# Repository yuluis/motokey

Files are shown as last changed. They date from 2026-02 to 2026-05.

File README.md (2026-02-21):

# MotoKey — Aftermarket E-Moto Security System

Encrypted keycard lock for electric motorcycles. Cut the power, pocket the key.

**Live site:** https://kindro.store
**Hardware design:** https://kindro.store/hardware-design.html

---

## What Is This

MotoKey is an aftermarket security system for electric mopeds/motorcycles/scooters. It's a small weatherproof box that wires inline with the battery and cuts power unless an encrypted key fob is nearby. No key = no power = bike doesn't move.

Every kit ships with:
- 1 lock box (mounts on bike, inline with battery)
- 2 encrypted key fobs (pocket/keychain sized)
- Mounting kit (bracket, zip ties, adhesive, wire terminals, heat shrink)
- Instruction card with QR link to install video

Two products:
| Product | Price | Key Difference |
|---|---|---|
| **MotoKey Basic** | $89 | AES-128, single relay, CR2032 fob, 30ft range |
| **MotoKey Enhanced** | $149 | AES-256, dual relay + tamper alert, USB-C fob, 50ft range, 3 fobs |

---

## Origin

This project started as a learning exercise between Luis and Julio on 2026-02-21. The goal: use AI (Claude) to go from idea to live website to hardware design in a single session.

**The conversation:**
- Julio builds aftermarket e-motos and wanted a keycard security system to sell
- Start with two versions: a basic remote and an enhanced remote
- Key fobs should be small (keychain/pocket dongle)
- The lock box connects to the battery with a simple power-cut circuit
- Must be weatherproof (outdoor bike use)
- Programming between keycard and hardware must be secured to prevent hacking
- Comes with 2 keys and a mounting kit

**What got built in this session:**
1. Product storefront website (static HTML/CSS/JS)
2. Full hardware architecture with real component selection
3. Security protocol design (AES-128 rolling codes, challenge-response)
4. Bill of materials with per-unit costs
5. Margin analysis proving profitability at $89/$149
6. Pushed to GitHub, deployed to production at kindro.store

---

## How It Works

### The Lock Box

Wires inline with the bike's main battery positive cable. Contains:
- **ATmega328P** microcontroller (same chip as Arduino)
- **SYN480R** 433MHz RF receiver
- **JQX-62F** 80A automotive relay (normally OPEN = locked)
- **LM2596** buck converter (48-72V battery → 5V logic)
- **AT24C256** EEPROM (stores up to 8 paired key records)
- Status LED + recessed pair button

The relay defaults to **open** (no power). When a valid key fob signal is received, the relay closes and power flows. When the key fob is out of range for 30 seconds, the relay opens and the bike is locked.

Cutting the wires doesn't help — the relay is normally open, so cutting anything just keeps the bike dead.

### The Key Fob

Small enough for a keychain. Contains:
- **ATtiny85** microcontroller (1.8μA sleep current)
- **SYN115** 433MHz RF transmitter
- **CR2032** coin cell battery (~18 month life)
- Single button

Press the button → MCU wakes from sleep → encrypts (counter + device ID) with the shared AES key → transmits 16-byte packet → goes back to sleep. Total active time: ~50ms.

### Security Protocol

**Pairing (one-time):**
1. Press PAIR button on lock box (LED blinks fast)
2. Press button on key fob
3. Lock box generates random 128-bit key
4. Key transfers to fob via physical contact (NFC/wired — can't intercept from distance)
5. Both devices store shared secret + set counter to 0

**Unlock (every use):**
1. Fob increments counter, encrypts (counter + fob ID) with shared key
2. Transmits encrypted packet over 433MHz
3. Lock box decrypts, verifies fob ID, checks counter > last seen
4. If valid: close relay (power on), start 30-sec timeout

**Why it's secure:**
- **Replay attack** → Fails. Counter already advanced. Old codes rejected.
- **Brute force** → AES-128 = 3.4×10³⁸ possible keys. Would take 10²² years at 1 billion attempts/sec.
- **Signal capture** → Every packet looks like random noise. No patterns.
- **Physical tamper** → Electronics potted in epoxy. Cracking the box destroys the circuits.
- **Wire bypass** → Relay is normally open. Cutting wires = bike stays dead.

---

## Economics

### Bill of Materials (at 100 units)

**Lock Box:** $10.80
| Component | Part | Cost |
|---|---|---|
| MCU | ATmega328P-AU | $1.40 |
| RF Receiver | SYN480R 433MHz | $0.50 |
| Relay | JQX-62F 80A | $2.80 |
| Relay Driver | 2N2222A + 1N4007 | $0.10 |
| Voltage Reg | LM2596 buck module | $0.80 |
| EEPROM | AT24C256 | $0.25 |
| Crystal | 16MHz + caps | $0.15 |
| LED + Button | Bicolor + tactile | $0.18 |
| Screw Terminals | 5mm pitch x2 | $0.30 |
| Wire Leads | 10AWG silicone x2 | $0.60 |
| Antenna | 17cm wire | $0.02 |
| PCB | 2-layer 50x40mm (JLCPCB) | $0.80 |
| Enclosure | ABS IP65 80x60x30mm | $1.80 |
| Cable Glands | PG7 nylon x2 | $0.20 |
| Potting | Urethane 2-part ~30ml | $0.50 |
| Misc | Caps, resistors, header | $0.40 |

**Key Fob (x1):** $2.37
| Component | Part | Cost |
|---|---|---|
| MCU | ATtiny85-20SU | $0.65 |
| RF Transmitter | SYN115 433MHz | $0.35 |
| Battery Holder | CR2032 SMD | $0.12 |
| Battery | CR2032 | $0.20 |
| Button | Tactile SMD 4x4mm | $0.05 |
| PCB | 2-layer 35x20mm | $0.40 |
| Enclosure | ABS fob case + keyring | $0.45 |
| Misc | Caps, resistors | $0.15 |

**Mounting Kit:** $1.60 | **Packaging:** $1.20

### Margin Analysis

| | Basic ($89) | Enhanced ($149) |
|---|---|---|
| BOM + materials | $18.34 | $31.10 |
| Assembly + QC | $5.00 | $8.25 |
| **Total COGS** | **$23.34** | **$39.35** |
| **Gross margin** | **$65.66 (73.8%)** | **$109.65 (73.6%)** |

At even 10 hand-built units ($30 COGS), the Basic still clears $59/unit.

---

## Next Steps for Julio

### Phase 1: Prototype (Weekends 1-2) — ~$35

Buy from Amazon/AliExpress:
- Arduino Nano (ATmega328P dev board) — $5
- 433MHz TX/RX module pair — $3
- 80A automotive relay module — $6
- ATtiny85 dev board (Digispark) — $4
- LM2596 buck converter module — $2
- Breadboard + jumper wires — $5
- CR2032 battery + holder — $2
- Push buttons + LEDs + resistors — $3
- ABS project box — $3
- Key fob cases (2-pack) — $2

Also need (one-time): USB-ASP programmer (~$8), soldering iron if you don't have one.

**Weekend 1: Proof of concept**
- Wire Arduino Nano + relay on breadboard
- Wire ATtiny85 + 433MHz TX on second breadboard
- Write basic TX/RX code (no encryption yet)
- Goal: press fob button → relay clicks → LED lights up

**Weekend 2: Add security**
- Add AES-128 library to both MCUs (use `tiny-AES-c` library)
- Hardcode a shared test key
- Implement rolling counter
- Verify that replaying a captured signal is rejected

### Phase 2: Complete Product (Weekends 3-4)

**Weekend 3: Pairing + polish**
- Add pair button logic on lock box
- Implement key exchange (wired connection for prototype)
- Add LED status states (green=unlocked, red=locked, blink=pairing)
- Add 30-second auto-lock timeout
- Add EEPROM storage for paired keys (support up to 8)

**Weekend 4: Enclosure + real test**
- Solder onto perfboard (replace breadboard)
- Mount in ABS project box with cable glands
- Fit fob circuit into key fob case
- Test with actual e-moto (or 48V bench supply)
- Range test through walls (target: 20-30m)
- Seal with potting compound

### Phase 3: First Production Run (Week 5-6)

- Order custom PCBs from JLCPCB (5-day turnaround, ~$0.80/board at 100 qty)
- Order components from LCSC (ships with PCBs)
- Assemble 10 units
- Create install video (phone camera is fine, post to YouTube)
- Print instruction cards with QR code to video

### Phase 4: Website + Sales

- Update kindro.store with real product photos
- Add Stripe payment integration (or start with PayPal/Venmo for simplicity)
- Post on e-moto forums, Facebook groups, Reddit r/ebikes r/emotorcycles
- List on eBay/Amazon if volume justifies it

---

## Plan to Sell the First 10 Units

### Target Customer
Owners of Chinese-brand electric mopeds/scooters (Onyx, Monday Motorbikes, Super73-adjacent, Sur-Ron, Talaria, generic 48V-72V e-motos) who currently have zero theft protection.

### Pricing Strategy
- **Launch price: $79 Basic / $129 Enhanced** (introductory discount)
- After first 10 units and reviews: raise to $89 / $149
- Bundle deal: Basic + Extra Fob 2-pack for $99

### Sales Channels (ranked by effort vs return)

**1. E-moto Facebook groups (free, highest conversion)**
- Join: "Sur-Ron Owners Group", "Onyx Motorbikes Owners", "Electric Motorcycle Riders", "E-bike Security"
- Post a demo video: "I made an aftermarket kill switch for my [bike]. Press fob = power. Walk away = dead. $79."
- Engage with theft complaint posts (there are many)
- Offer first 5 buyers a discount for honest reviews

**2. Reddit (free, wide reach)**
- r/ebikes (750K+ members), r/surron, r/emotorcycles, r/ElectricScooters
- Post as "I built this" with demo video/gif
- Link to site in comments (not title — Reddit hates direct sales posts)

**3. Local e-moto shops / repair shops**
- Leave 2 demo units at local shops on consignment
- They sell for $89, keep $15 commission
- Julio's existing network of people who build aftermarket e-motos

**4. eBay listing**
- Low effort to set up
- "Electric Motorcycle Security Kill Switch - Encrypted Key Fob - Aftermarket Anti-Theft"
- eBay takes ~13% but handles payments and provides buyer trust

**5. YouTube install video**
- Film installing MotoKey on an actual e-moto (3-5 min)
- Title: "DIY Anti-Theft for Electric Motorcycles - $79 Kill Switch Install"
- Description links to kindro.store
- This becomes the long-tail discovery channel

### First 10 Units — Concrete Plan

| Unit | Channel | Price | Notes |
|---|---|---|---|
| 1 | Personal use / demo | $0 | Install on Julio's bike for demo videos |
| 2 | Consignment at local shop | $89 | Leave with a shop Julio trusts |
| 3-5 | Facebook groups | $79 | Launch price, ask for reviews |
| 6-7 | Reddit posts | $79 | Link to kindro.store |
| 8 | eBay | $89 | Test marketplace demand |
| 9-10 | Word of mouth / referral | $79 | Offer $10 referral to early buyers |

### Revenue from first 10

| | Units | Revenue |
|---|---|---|
| Demo unit | 1 | $0 |
| At $79 | 7 | $553 |
| At $89 | 2 | $178 |
| **Total** | **10** | **$731** |
| COGS (10 units @ ~$30 hand-built) | | -$300 |
| **Net profit** | | **$431** |

That $431 funds the next batch of 25-50 units at proper PCB pricing, which drops COGS to ~$23/unit and margin jumps to 74%.

### Marketing Assets Needed
1. **Demo video** (30 sec): Press fob → bike powers on. Walk away → bike dies. Film on actual e-moto.
2. **Install video** (3-5 min): Full install process. Phone camera is fine.
3. **Product photos**: Lock box, fobs, complete kit in packaging. Natural light, clean background.
4. **One-liner**: "Encrypted kill switch for your e-moto. $79. Two keys included."

---

## Tech Stack (Website)

- Static HTML + CSS + JavaScript (no framework, no build step)
- Hosted on DigitalOcean VPS behind nginx
- Domain: kindro.store (SSL via Let's Encrypt)

---

## Repository Structure

```
motokey/
├── index.html              # Product storefront
├── style.css               # Storefront styles
├── app.js                  # Cart + FAQ interactivity
├── hardware-design.html    # Full hardware architecture document
├── .gitignore
└── README.md               # This file
```

---

## Built With

This entire project — website, hardware architecture, security protocol, BOM, margin analysis, and go-to-market plan — was designed in a single AI-assisted session using [Claude Code](https://claude.com/claude-code).

The goal was to demonstrate how to go from conversation to live product in one sitting:
1. Discussed the idea → 2. Built the website → 3. Pushed to GitHub → 4. Deployed to production → 5. Designed the hardware → 6. Wrote the business plan

Total time: one session. Total code written by hand: zero.

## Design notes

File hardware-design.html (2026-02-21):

← Back to storefront

# MotoKey Hardware Architecture

MVP design with real components. Goal: build cheap, sell profitably at $89 / $149.

## 1 System Overview

The whole system is three things: a lock box on the bike, a key fob in your pocket, and a security protocol binding them together. That's it.

Key Design Decision:

One-way RF (fob transmits, box receives). This is half the cost of two-way communication and the fob battery lasts 3x longer. The tradeoff: no confirmation beep from the bike. The LED on the lock box blinks instead. For $89, this is the right call.

## 2 Lock Box Architecture

## 3 Key Fob Architecture

## 4 Security Protocol

This is what prevents someone from cloning the fob or replaying a captured signal.

### Pairing (one-time setup)

  FOB                                    LOCK BOX
   │                                        │
   │  1. User presses PAIR button on box    │
   │         LED blinks fast (green)        │
   │                                        │
   │  2. User presses FOB button            │
   │  ──── plaintext: "PAIR_REQUEST" ─────► │
   │                                        │
   │  3. Box generates random 128-bit key   │
   │     Box stores: KEY + FOB_ID           │
   │     Box shows LED pattern:             │
   │     (4 blinks = key byte checksum)     │
   │                                        │
   │  4. Box transmits key via IR/NFC       │
   │  ◄──── one-time key transfer ────────  │  ← requires physical contact
   │                                        │
   │  5. Fob stores KEY in EEPROM           │
   │     Both set counter = 0               │
   │                                        │
   │  DONE. Shared secret established.      │
   └────────────────────────────────────────┘

   NOTE: Key transfer via NFC/physical contact means an attacker
   cannot intercept the pairing from a distance. You must be
   holding the fob against the box.

### Unlock (every use)

  FOB                                    LOCK BOX
   │                                        │
   │  1. User presses button                │
   │     Fob increments counter             │
   │     Fob computes:                      │
   │       payload = counter | FOB_ID       │
   │       encrypted = AES-128(KEY, payload)│
   │                                        │
   │  ──── 433MHz: encrypted packet ──────► │
   │       (16 bytes, ~3ms air time)        │
   │                                        │
   │  2. Box decrypts with stored KEY       │
   │     Checks FOB_ID matches              │
   │     Checks counter > last_counter      │
   │     If valid:                          │
   │       - Update last_counter            │
   │       - Close relay (power ON)         │
   │       - Start 30-second timeout        │
   │       - LED solid green                │
   │                                        │
   │  3. After 30 sec with no new signal:   │
   │     - Open relay (power OFF)           │
   │     - LED blink red                    │
   │                                        │
   └────────────────────────────────────────┘

### Why this is hard to hack

#### Replay Attack

Attacker records a valid transmission and replays it. Fails because the counter has already advanced. The lock box rejects any counter ≤ last seen.

#### Brute Force

AES-128 has 2¹²⁸ possible keys = 3.4 × 10³⁸. At 1 billion attempts/second, it would take 10²² years. The universe is 1.4 × 10¹⁰ years old.

#### Signal Analysis

Every transmission looks like random noise. No pattern emerges even with millions of captured packets. AES is the same encryption used by the US government for classified data.

#### Physical Bypass

Relay is normally-open. Cutting wires = no power. Cracking the potted enclosure destroys the PCB. The only bypass is splicing around the entire box, which requires stripping the bike apart.

## 5 Bill of Materials & Cost

### Lock Box BOM

Component | Part | Qty | Unit Cost | Notes
MCU | ATmega328P-AU (TQFP) | 1 | $1.40 | Same chip as Arduino. Massive ecosystem, easy to program.
RF Receiver | SYN480R 433MHz | 1 | $0.50 | Superheterodyne ASK receiver. Better range than SRX882.
Relay | JQX-62F 80A SPST-NO | 1 | $2.80 | Automotive-grade. 12V coil. Handles 48-72V DC switching.
Relay Driver | 2N2222A + 1N4007 flyback | 1 | $0.10 | NPN transistor drives relay coil from MCU GPIO.
Voltage Regulator | LM2596 buck module | 1 | $0.80 | 48-72V input → 5V output. Pre-built module.
EEPROM | AT24C256 (I2C) | 1 | $0.25 | Stores up to 8 paired key records. Non-volatile.
Crystal | 16MHz + 22pF caps | 1 | $0.15 | MCU clock source.
LED | Bicolor red/green 3mm | 1 | $0.08 | Status indicator. Two resistors.
Button | Tactile switch (recessed) | 1 | $0.10 | Pairing button. Recessed to prevent accidental press.
Screw Terminals | 5mm pitch, 2-pos | 2 | $0.30 | Battery in + controller out. Accepts 10AWG.
Wire Leads | 10AWG silicone, 15cm ea | 2 | $0.60 | Pre-tinned, red + green.
Antenna | 17cm wire (1/4 wave) | 1 | $0.02 | Just a piece of wire. Cut to 17.3cm for 433MHz.
PCB | Custom 2-layer, 50x40mm | 1 | $0.80 | JLCPCB @ 100 qty. FR4, 1.6mm, HASL.
Enclosure | ABS IP65 box, 80x60x30mm | 1 | $1.80 | Off-shelf waterproof junction box. Black.
Cable Glands | PG7 nylon | 2 | $0.20 | Waterproof wire pass-through.
Potting Compound | Urethane 2-part | ~30ml | $0.50 | Fills enclosure. Tamper-proof + weather seal.
Misc | Caps, resistors, header, solder | - | $0.40 | Decoupling caps, pull-ups, ISP header.
Lock Box Subtotal | | | $10.80

### Key Fob BOM (x1)

Component | Part | Qty | Unit Cost | Notes
MCU | ATtiny85-20SU (SOIC) | 1 | $0.65 | 8-pin, 8KB flash. Runs AES in software. 1.8μA sleep.
RF Transmitter | SYN115 433MHz | 1 | $0.35 | ASK transmitter. 10mW. Tiny SOT-23 package.
Battery Holder | CR2032 SMD holder | 1 | $0.12 | Bottom-mount for thin profile.
Battery | CR2032 lithium | 1 | $0.20 | Included. 225mAh, ~18 month life.
Button | Tactile SMD 4x4mm | 1 | $0.05 | Main unlock button. Wake from sleep.
Antenna | PCB trace | 1 | $0.00 | Etched into PCB. No extra cost.
PCB | Custom 2-layer, 35x20mm | 1 | $0.40 | JLCPCB @ 100 qty. Small board.
Enclosure | ABS key fob case + keyring | 1 | $0.45 | Off-shelf injection molded fob case. Black.
Misc | Caps, resistors | - | $0.15 | Decoupling, pull-up.
Key Fob Subtotal (x1) | | | $2.37

### Mounting Kit BOM

Component | Part | Qty | Unit Cost | Notes
Mounting Bracket | Stainless L-bracket | 1 | $0.40 | Screw-mount to frame.
Zip Ties | UV-resistant nylon, 200mm | 6 | $0.15 | Backup / alternative mounting.
Adhesive Pad | 3M VHB double-sided | 1 | $0.30 | For flat-surface mounting.
Heat Shrink | Assorted, adhesive-lined | 4pc | $0.20 | Weatherproof wire splices.
Ring Terminals | 10AWG, M6 | 4 | $0.40 | Optional: bolt directly to battery terminals.
Instruction Card | Printed card, double-sided | 1 | $0.15 | Install guide + QR to video.
Mounting Kit Subtotal | | | $1.60

### Packaging

Component | Part | Qty | Unit Cost | Notes
Box | Custom printed corrugated | 1 | $0.80 | Branded box, 150x120x60mm
Insert | Die-cut foam insert | 1 | $0.40 | Holds lock box + 2 fobs + kit
Packaging Subtotal | | | $1.20

## 6 Cost Rollup & Margin Analysis

### MotoKey Basic — Retail $89

Line Item | Cost
Lock Box (assembled) | $10.80
Key Fob x 2 | $4.74
Mounting Kit | $1.60
Packaging | $1.20
Assembly labor (15 min @ $15/hr) | $3.75
Testing & QC (5 min) | $1.25
Total COGS | $23.34
Retail Price | $89.00
Gross Margin | $65.66 (73.8%)

### MotoKey Enhanced — Retail $149

Line Item | Cost
Lock Box (upgraded: dual relay, STM32L4, vibration sensor) | $16.50
Key Fob x 2 (USB-C rechargeable, LED) + 1 backup fob (basic) | $11.20
Mounting Kit | $1.60
Packaging (premium) | $1.80
Assembly labor (25 min @ $15/hr) | $6.25
Testing & QC (8 min) | $2.00
Total COGS | $39.35
Retail Price | $149.00
Gross Margin | $109.65 (73.6%)

Prototype pricing note:

BOM costs above assume ordering 100 units from LCSC/JLCPCB. For a single prototype, expect 2-3x these prices (~$50-60 for one complete Basic kit from Mouser/DigiKey). But the per-unit math works beautifully at even small scale. At 100 units you're already at 73% margin.

## 7 First Prototype — What to Buy

To build one working prototype on your desk for under $40:

### Shopping List (DigiKey/Amazon/AliExpress)

Item | Source | ~Price
Arduino Nano (ATmega328P dev board) | Amazon | $5
433MHz TX/RX module pair (SYN115 + SYN480R) | Amazon/AliExpress | $3
5V 80A relay module (automotive) | Amazon | $6
ATtiny85 dev board (Digispark) | Amazon | $4
LM2596 buck converter module | Amazon | $2
Breadboard + jumper wires | Amazon | $5
CR2032 battery + holder | Amazon | $2
Push buttons (assorted) | Amazon | $2
LED + resistors | Amazon | $1
ABS project box | Amazon | $3
Key fob cases (2-pack) | AliExpress | $2
Prototype Total | | ~$35

Dev tools you'll also need (one-time):

USB-ASP programmer for the ATtiny85 (~$8). The Arduino Nano programs via USB directly. Soldering iron if you don't have one. Total one-time tool cost: ~$20-30.

### Prototype Build Order

  PHASE 1: Proof of Concept (Weekend 1)
  ──────────────────────────────────────
  ✦ Wire Arduino Nano + relay on breadboard
  ✦ Wire ATtiny85 + 433MHz TX on breadboard
  ✦ Write simple TX/RX code (no encryption yet)
  ✦ Press button on fob → relay clicks → LED turns on
  ✦ SUCCESS = "it works" demo

  PHASE 2: Security Layer (Weekend 2)
  ──────────────────────────────────────
  ✦ Add AES-128 library to both MCUs
  ✦ Hardcode a shared key for testing
  ✦ Implement rolling counter
  ✦ Verify: replaying a captured signal fails
  ✦ SUCCESS = "it's secure" demo

  PHASE 3: Pairing + Polish (Weekend 3)
  ──────────────────────────────────────
  ✦ Add pair button logic
  ✦ Implement key exchange (wired for prototype, NFC for production)
  ✦ Add LED status states
  ✦ Add 30-second auto-lock timeout
  ✦ Add EEPROM storage for paired keys
  ✦ SUCCESS = complete working unit

  PHASE 4: Enclosure + Test (Weekend 4)
  ──────────────────────────────────────
  ✦ Solder onto perfboard (ditch breadboard)
  ✦ Mount in ABS enclosure
  ✦ Fit fob PCB in key fob case
  ✦ Test with actual e-moto battery (48V bench supply or real bike)
  ✦ Range test (should get 20-30m through walls)
  ✦ SUCCESS = "ship it" prototype

## 8 Physical Layout

### Lock Box (top view, lid off)

┌──────────────────────────────────────────┐
│  ○ PAIR            ○ LED                 │  ← lid (buttons/LED)
│  btn               R/G                   │
├──────────────────────────────────────────┤
│                                          │
│  ┌─────────────┐  ┌───────────────────┐  │
│  │  LM2596     │  │   ATmega328P      │  │
│  │  buck       │  │   + crystal       │  │
│  │  48V→5V     │  │   + EEPROM        │  │
│  └─────────────┘  │   + SYN480R RX    │  │
│                    │                   │  │
│                    │         ┌antenna  │  │
│                    └────────┘         ─┤  │
│                                          │
│  ┌──────────────────────────────────┐    │
│  │                                  │    │
│  │      JQX-62F  80A  RELAY        │    │
│  │                                  │    │
│  └──────────────────────────────────┘    │
│                                          │
│  [RED IN]                    [GREEN OUT]  │  ← screw terminals
│    ║                              ║      │    through cable glands
└════╩══════════════════════════════╩══════┘
     ↑                              ↑
   BAT+                          CTRL+
   10AWG                         10AWG

### Key Fob (internal view)

    ○ ← keyring hole
┌──────────────────────┐
│                      │
│  ┌────────────────┐  │
│  │    ATtiny85    │  │
│  │                │  │
│  │  ┌──────────┐  │  │
│  │  │ SYN115   │  │  │
│  │  │ TX       │  │  │
│  │  └──────────┘  │  │
│  │                │  │
│  │  ~~~antenna~~  │  │  ← PCB trace
│  └────────────────┘  │
│                      │
│  ┌────────────────┐  │
│  │   CR2032       │  │  ← coin cell
│  │   battery      │  │    (bottom mount)
│  └────────────────┘  │
│                      │
│       [ BTN ]        │  ← main button
│                      │
└──────────────────────┘
   48mm x 30mm x 10mm

## 9 Scaling Considerations

#### 10 units (garage batch)

Hand-solder perfboard. Buy parts from Amazon. COGS ~$30/unit. Margin ~66% at $89.

#### 100 units (first real run)

Custom PCB from JLCPCB ($0.80/ea). Parts from LCSC. COGS ~$23/unit. Margin ~74% at $89.

#### 1000+ units

PCBA assembly (JLCPCB SMT). Custom injection mold enclosure. COGS drops to ~$15/unit. Margin ~83%.

Bottom line:

The Basic kit costs $23 to build at 100 qty and sells for $89. That's a 73% gross margin. Even selling 10 hand-built units at $30 COGS, you clear $59 per unit. The math works at every scale.

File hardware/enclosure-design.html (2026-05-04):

# MotoKey Lock Box — Enclosure Design v3

3D-printed castellated finger joint enclosure | 140x75x38mm | No drilling, no supports | 2026-03-11

## 1. Enclosure Overview

### External Dimensions

Length | 140 mm
Width | 75 mm
Height | 38 mm
Wall thickness | 2.5 mm
Corner radius | 3 mm
Split height | 19 mm

### Finger Joint

Finger width | 8 mm
Finger depth | 8 mm
Tolerance | 0.2 mm/side
Corners | Front/back own corners
Openings | 7 (auto at connectors)
Alignment | 2x 3mm pins

### Printing

Material | PETG or ABS
Layers | 0.2 mm
Walls | 3 perimeters
Infill | 20%
Supports | None needed
Orientation | Both open-side-up

## 2. Top View — Internal Layout with Modules

Top view with lid removed. GPS shown dashed because it mounts on the lid interior (faces sky). LoRa plugs into J4 header on PCB. Battery in printed cradle held by zip ties.

## 3. Side Cross-Section — Module Heights

Cross-section along long axis. Relay is tallest at 16mm. LoRa module sits on 8mm header pins. GPS mounts flat on lid interior with ceramic patch facing up (through plastic). Battery sits in printed cradle beside PCB.

## 4. Module Details

### LoRa — RFM95W

Module | RFM95W / Ra-01
Size | 16 x 16 x 3 mm
Interface | SPI (J4, 1x8 header)
Frequency | 915 MHz (US)
Antenna | Wire whip ~82mm
Position | Center-left of PCB
Height | ~11mm above PCB
Cost | ~$4

Plugs into J4 pin header. Keep away from relay (noise). Antenna runs along inside of enclosure wall. Optional: SMA bulkhead for external antenna.

### GPS — BN-220

Module | BN-220 / Quectel L80
Size | 22 x 20 x 6 mm
Interface | UART (J8, 1x4 header)
Antenna | Ceramic patch (integrated)
Position | Lid interior, front-left
Mount | Double-sided tape / shelf
Cable | ~60mm wire to J8
Cost | ~$5

Patch antenna MUST face sky. Plastic lid is RF-transparent. Mount flat against lid interior. Short cable to J8 on PCB.

### Battery — 18650

Cell | 18650 Li-ion
Size | 65 x 18 mm
Capacity | 2600 mAh typical
Charging | MCP73831 via USB
Position | Right side of enclosure
Mount | Printed cradle + 2x zip ties
Wires | 20AWG to BT1 pads
Runtime | ~50 hrs standby

Drops into semi-circular cradle. End walls prevent sliding. Two zip ties at 25% and 75% thread through floor channels and cinch over cell.

## 5. RF Placement Strategy

Key principle: GPS and LoRa in the quiet left zone, relay and buzzer in the noisy right zone, battery acts as a passive RF buffer between them. GND copper pour on both PCB layers provides shielding.

## 6. Wall Openings Map

### Front Wall (y = 0)

Opening | Position | Width | Purpose
Cable 1 | x = 49 | 10 mm | Sensor wires
Cable 2 | x = 84 | 10 mm | Zone wires

### Back Wall (y = 75)

Opening | Position | Width | Purpose
J1 | x = 20 | 12 mm | 12V power input
LEDs | x = 53 | 18 mm | LED1 + LED2 light pipes
J2 | x = 96 | 12 mm | Relay COM/NO/NC

### Left Wall (x = 0)

Opening | Position | Width | Purpose
J7 | y = 31 | 14 mm | USB Micro-B charging

### Right Wall (x = 140)

Opening | Position | Width | Purpose
Battery | y = 37.5 | 10 mm | Battery wire routing

## 7. Bill of Materials — Enclosure + Modules

Item | Qty | Spec | Est. Cost
3D printed base | 1 | 140x75x19mm, PETG/ABS | $3-5
3D printed lid | 1 | 140x75x19mm, PETG/ABS | $3-5
RFM95W LoRa module | 1 | SX1278, 915MHz, SPI | $4
BN-220 GPS module | 1 | Integrated patch antenna, UART | $5
18650 Li-ion cell | 1 | 2600mAh, unprotected | $3
Wire antenna | 1 | ~82mm for 915MHz quarter-wave | $0
Zip ties (small) | 2 | 100mm, for battery hold-down | $0.10
M3x8 self-tap screws | 4 | PCB standoff (optional, friction fit) | $0.20
Double-sided tape | 1 | 3M VHB, for GPS on lid | $0.10
20AWG wire | 100mm | Battery leads (red + black) | $0.05
Total enclosure + modules + battery | | | $18-22

## 8. Assembly Notes

- No drilling. All openings are formed by finger joint gaps — printed in place.
- No supports. Both pieces print open-side-up. All features are vertical extrusions.
- Mount PCB on 4x standoffs in base (press-fit or self-tap M3 screws)
- Plug LoRa module (RFM95W) into J4 header. Route antenna wire along left wall interior.
- Stick GPS module (BN-220) to lid interior with VHB tape, front-left corner. Cable to J8.
- Drop 18650 cell into cradle. Thread 2x zip ties through floor channels, cinch over cell.
- Solder battery wires (20AWG, 50mm) from cell to BT1 pads on PCB
- Route power wires (12V, relay) through back wall openings
- Press lid down — fingers interleave with base, alignment pins register position
- Optional: seal finger joint seams with silicone for weather resistance

For weather sealing: apply a thin bead of silicone to finger joint faces before closing. The tight finger mesh plus silicone provides good water resistance without gaskets.

MotoKey enclosure design v3 — 2026-03-11 | CAD: enclosure.scad (OpenSCAD)

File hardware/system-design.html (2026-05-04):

# MotoKey Controller — System Design

Generic encrypted rolling-code relay controller. Use cases: e-motorcycle kill switch, deadbolt lock, gate controller. Phase 1 (KeeLoq fob + buzzer) and Phase 2 (LoRa remote access).

## 1. The Problem

MotoKey is a generic encrypted rolling-code relay controller. The same PCB and firmware serves multiple use cases — the only difference is the enclosure and wiring harness.

E-Motorcycle Kill Switch

E-motos (Sur-Ron, Talaria, Zero, NIU) have no ignition key — they use a simple toggle switch or app. MotoKey intercepts the motor controller enable wire so the bike won't move without the owner's key fob.

Deadbolt / Gate Lock

Same controller drives an electric strike or motorized deadbolt. Relay output replaces the enable wire with the lock's power circuit. Walk-up fob unlock + optional LoRa remote access.

## 2. Where It Mounts

Installation Location

- Under the seat — every e-moto has space here, accessible for install, hidden from thieves
- Zip-tied or velcro-strapped to the frame — no drilling required
- Near the existing motor controller — short wire run to intercept the enable line
- Antenna wire routed up toward seat hinge for best RF reception

Critical Design Insight: Intercept the Enable Wire, NOT the Power Wire

E-motos run 48-72V at 40-100A to the motor. You do NOT want a relay switching that. Instead, every motor controller has a low-current enable/key wire (the existing ignition switch). MotoKey's relay (10A @ 5V) switches this enable wire. When the relay is open (armed), the motor controller stays off regardless of the main power switch.

## 3. Form Factor

Parameter | Spec
Enclosure size | 80 x 50 x 25 mm (fits in palm)
Material | ABS plastic, ultrasonic welded
Weight | ~65g including potting
Mounting | 4x M3 tabs + zip-tie slots (no drilling)
Sealing | Silicone gasket + potting compound
Cable entry | 2x PG7 cable glands with O-rings
LED | Visible through translucent window on top face
Learn button | Recessed pinhole (paperclip to press)

## 4. Main Interfaces

Interface | Connector | Purpose
J1 — Power | 2-pin screw terminal | 12V from e-moto accessory circuit
J2 — Relay Out | 3-pin screw terminal (COM/NO/NC) | Intercepts motor controller enable wire
J4 — Radio Module | 8-pin header | SX1278 LoRa/ASK module: VCC, GND, SPI bus (MOSI/MISO/SCK/NSS), RST, DIO0 (IRQ)
J3 — ICSP | 2x3 pin header | Factory firmware programming (internal)
SW1 — Learn | Pinhole tactile switch | Pair new key fobs
LED1/LED2 | Through translucent window | Red = armed, Green = unlocked
BZ1 — Buzzer | Passive piezo (on-board) | Audible beep (lock) / double-beep (unlock) confirmation
J5 — E-Paper (opt.) | 8-pin header | 1.54" e-ink display: VCC, GND, SPI (MOSI/SCK), CS, DC, RST, BUSY. Shows QR code for payments.
J6 — Zone Inputs | 7-pin header | 5 digital inputs (ZONE1-5) for NO/NC contact sensors (reed switches, door/window). +5V and GND for sensor power.
TH1 — Temp Sensor | On-board NTC | 10k NTC thermistor voltage divider on ADC6. Ambient temperature monitoring.
R8 — Light Sensor | On-board LDR | Photoresistor voltage divider on ADC7. Tamper detection (enclosure opened = light detected).
J8 — GPS (opt.) | 4-pin header | GPS receiver module: VCC, GND, TX→PD0(RXD), RX←PD1(TXD). Shares PD0/PD1 with ZONE3/ZONE4 — firmware selects mode.
J7 — USB Charge | USB Micro-B | LiPo battery charging input via MCP73831 (500mA). Charge only — no data lines.
BT1 — Battery | LiPo 3.7V cell | Optional backup battery. Powers system via Schottky diode-OR when 12V absent (~3.4V low-power mode).

## 5. How the User Uses It

## 6. Lock / Unlock State Machine

Fail-Secure Design

Power on → ARMED (relay open, motor disabled). This is the critical safety property. If power is lost, cut, or the controller fails, the relay opens and the bike can't move. A thief cannot bypass MotoKey by cutting its power wire — that just makes the bike more locked.

The ONLY way to enable the relay is: valid KeeLoq rolling code from a paired fob (or LoRaWAN command in Phase 2).

## 7. Diagnostics — LED + Buzzer

Two LEDs (red + green) visible through the enclosure window and a passive piezo buzzer (BZ1) communicate all states. The buzzer is driven by PWM on PD6 (OC0A) — different tone frequencies distinguish events.

LED Pattern | Buzzer | Meaning | User Action
RED solid | — | Armed (normal) | Press fob to unlock
GREEN solid | — | Unlocked (normal) | Ride. Press fob to lock.
GREEN flash (1x) | Double-beep (high tone) | Fob accepted → UNLOCK | State changed to unlocked
RED flash (1x) | Single beep (low tone) | Fob accepted → LOCK | State changed to armed
RED flash (3x) | Three short buzzes | Fob rejected (unknown or replay) | Try again or re-pair
RED+GREEN alternating fast | Rapid chirps | Pairing mode (10 sec window) | Press fob to pair
GREEN (2 sec) | Rising tone | Pairing success | Done — fob stored
RED slow blink (1 Hz) | — | Low voltage (< 10V) | Check 12V connection
OFF | — | No power | Check 12V connection

Audible Feedback — Why It Matters

You can't always see the LED. The bike is under a cover, the deadbolt is around a corner, or you're walking away in sunlight. The buzzer gives instant confirmation without looking: one beep = locked, two beeps = unlocked. Same mental model as a car key fob. Total cost: ~$0.30 (passive piezo + 100Ω resistor).

Implementation: BZ1 is a passive piezo buzzer driven via R5 (100Ω current limit) from PD6/OC0A. Timer0 generates PWM at different frequencies: 2.7 kHz for "lock" tone, 4 kHz for "unlock" tone. No amplifier needed — passive piezo at 5V is audible at 3+ meters.

Why LED + Buzzer Is Enough

No screen, no app, no Bluetooth. Two LEDs + one buzzer + one button. A rider parked on the street needs to know exactly two things: "is it armed?" and "did my fob work?" Sound confirms without looking. Everything else is a one-time setup event.

## 8. Weather Resistance

Layer | Protection | Spec
Enclosure | ABS plastic, ultrasonic-welded seam | IP67 (dust-tight, submersible 1m/30min)
Gasket | Silicone O-ring between shell halves | -40°C to +200°C range
Cable entry | PG7 cable glands with compression seal | IP68 per gland
PCB coating | Acrylic conformal coating (MG Chemicals 419D) | Moisture, salt spray, vibration
Potting | Silicone potting compound fills enclosure | Vibration damping + waterproof backup
LED window | Translucent polycarbonate, glued with silicone | UV-stable, sealed
Operating temp | -20°C to +60°C | Covers all riding conditions

Why IP67 Matters for E-Motos

E-motos are ridden in rain, parked outdoors, and pressure-washed. Under-seat areas get splash, puddle spray, and condensation. IP65 (jet spray) is minimum; IP67 (brief submersion) gives margin for the real world.

## 9. Phase 1 / Phase 2 Roadmap

Phase 1 KeeLoq Fob + Buzzer

- SX1278 in ASK mode — demodulates 433 MHz KeeLoq rolling codes from off-the-shelf HCS301 fobs ($3 each)
- Passive piezo buzzer — single beep (lock), double-beep (unlock), error buzz
- Two status LEDs — red (armed) + green (unlocked)
- Learn button — pair up to 4 fobs, 10-sec hold to erase all
- Fail-secure relay — power-on = armed, relay open
- No internet required. No gateway. No app.

Phase 2 LoRa Remote Access

- SX1278 switches to LoRa mode when not listening for fobs — time-shared radio
- LoRaWAN uplink: lock state, battery voltage, temperature, tamper events → TTN → cloud dashboard
- LoRaWAN downlink: remote lock/unlock commands from phone via TTN cloud
- Range: 2-5 km urban, 10+ km line-of-sight (vs 10m for fob)
- Requires a LoRaWAN gateway ($50-100 or public TTN coverage)
- AES-128 end-to-end encryption built into LoRaWAN spec
- Optional 1.54" e-paper display (J5) — shows QR code for Lightning/LNURL payment at laundry machines, vending, or gate access

E-Paper QR Display (J5) — Laundry Payment Flow

The optional 1.54" e-ink display (200x200 pixels, ~$5) connects via the 8-pin J5 header. It shares the SPI bus with the SX1278 radio (separate chip selects). The display draws zero power while showing an image — the QR code persists indefinitely.

How it works: The QR code encodes a static LNURL-pay endpoint (e.g., pay.motokey.io/m/DEVICE_ID). Tenant scans with any Lightning wallet → phone fetches a fresh invoice from your server → pays → server sends LoRaWAN downlink → relay enables machine for one cycle. The QR code on the display never changes — it's written once at firmware flash time.

Pin budget: PC2 (CS), PC3 (DC), PC4 (RST), PC5 (BUSY) — the last four available GPIO on the ATmega328P. SPI bus (MOSI/SCK) shared with SX1278 and ICSP. All 32 pins now assigned.

SX1278: One Radio, Two Modes

The SX1278 ($3) replaces the SYN480R ($0.50) from the original design. It's a multi-mode transceiver that can demodulate ASK (for KeeLoq fobs, 433 MHz) and LoRa (for long-range/LoRaWAN) — but not simultaneously. The firmware time-shares: listen for fobs in ASK mode (default), periodically switch to LoRa mode to check for downlink commands and send telemetry. Fob response latency stays under 100ms.

Same PCB, same headers. Phase 1 firmware only uses ASK mode. Phase 2 firmware adds LoRa time-sharing. No hardware change needed — J4 (SX1278) carries SPI + IRQ + RESET, J5 (e-paper) uses the remaining PC2-5 GPIO. All 32 ATmega328P pins are now assigned.

Battery Backup + USB Charging (Optional)

A MCP73831 single-cell LiPo charge controller (U3, SOT-23-5, $0.40) charges a 3.7V LiPo cell (BT1) from USB Micro-B (J7) at 500mA. A BAT54 Schottky diode (D3) provides automatic power-path switching:

- 12V present — LDO runs the system at 5V. Schottky is reverse-biased (3.7V < 5V). Battery charges independently from USB.
- 12V absent — LDO output drops. Battery feeds through Schottky at ~3.4V (3.7V − 0.3V drop). ATmega328P runs fine at 3.3V+ with 8MHz internal oscillator.
- Low-power mode — Firmware sleeps, wakes on timer/interrupts. Relay won't engage (needs 5V), but LoRa uplinks, sensor reads, and zone monitoring work. Ideal for standalone sensor nodes, tip jars, and water leak detectors.

COGS impact: +$3.70 (charger IC $0.40 + passives $0.80 + LiPo $2.50). Battery option adds value for deployments without permanent 12V power.

## 10. Mechanical Securing

Anti-Tamper Considerations

- Hidden installation — under seat, not visible from outside
- Cutting the MotoKey power wire → relay opens → bike stays disabled (fail-secure)
- Cutting the relay output wire → motor controller enable line is severed → bike disabled
- Bypassing by shorting relay output → requires finding the box AND hot-wiring the specific wire — same difficulty as hot-wiring the original ignition
- Potted PCB → can't probe or reprogram the MCU without destroying the board

## 10b. Sensors & Zone Inputs

Temperature Sensor (TH1 — NTC Thermistor)

A 10k NTC thermistor on ADC6 measures ambient temperature via voltage divider (R6 10k pullup to +5V). At 25°C the divider output is 2.5V (mid-range ADC). The Steinhart-Hart equation in firmware converts ADC counts to °C.

Use cases: Over-temperature alarm (e-moto battery bay), freeze warning (deadbolt/gate), environmental logging via LoRa telemetry. Phase 2 includes temperature in every uplink packet.

Light Sensor (R8 — LDR Photoresistor)

A photoresistor (LDR) on ADC7 with R7 10k pullup. In darkness (enclosure sealed), LDR resistance is >1MΩ → ADC reads near 5V. If the enclosure is opened, ambient light drops LDR resistance → ADC voltage drops sharply. A firmware threshold triggers a tamper alert.

Use cases: Enclosure tamper detection (someone opened the box), day/night detection for scheduling, light level logging. Combined with zone inputs, this creates a basic intrusion detection system.

Zone Inputs (J6 — 7-pin Header)

Five digital GPIO inputs (PB1, PB2, PD0, PD1, PD7) exposed on the J6 header alongside +5V and GND. Each input uses the ATmega328P's internal pullup resistor — external wiring is simple 2-wire (signal + GND). Connect any NO/NC contact sensor:

- Reed switches — door/window open/close detection (magnet-based, NO or NC)
- PIR motion sensors — wired PIR with relay output
- Water leak sensors — conductive probe, closes circuit when wet
- Vibration sensors — tilt/shock switches for tamper detection
- Panic buttons — wired NO pushbutton for manual alarm trigger

Phase 1: Zone state changes trigger buzzer alert pattern. Phase 2: Zone events generate immediate LoRa uplink with zone ID + state + timestamp. Combined with temp/light sensors, this turns the MotoKey controller into a basic security alarm panel.

Pin Budget — All 32 Pins Assigned

Port | Pin | Function
PB0 | 14 | LEARN button (input, pullup)
PB1 | 15 | ZONE1 input
PB2 | 16 | ZONE2 input
PB3-5 | 17-19 | SPI bus (MOSI/MISO/SCK) — shared ICSP, SX1278, e-paper
PB6-7 | 9-10 | XTAL1/XTAL2 (NC — using internal 8MHz osc)
PC0 | 23 | SX1278_NSS (chip select)
PC1 | 24 | SX1278_RST
PC2 | 25 | EPD_CS (e-paper chip select)
PC3 | 26 | EPD_DC
PC4 | 27 | EPD_RST
PC5 | 28 | EPD_BUSY
PC6 | 29 | RESET (with pullup)
PD0 | 30 | ZONE3 input or GPS RXD (UART receive)
PD1 | 31 | ZONE4 input or GPS TXD (UART transmit)
PD2 | 32 | RADIO_IRQ (INT0 — SX1278 DIO0)
PD3 | 1 | RELAY_DRV (NPN base via R1)
PD4 | 2 | LED1 (red — armed)
PD5 | 3 | LED2 (green — unlocked)
PD6 | 11 | BUZZER (OC0A PWM output)
PD7 | 12 | ZONE5 input
ADC6 | 19 | TEMP_SENSE (NTC thermistor)
ADC7 | 22 | LIGHT_SENSE (LDR photoresistor)
VCC, AVCC, GND×3, AREF | — | Power rails

## 11. Requirements

### Functional Requirements

ID | Requirement | Priority
F-01 | Accept KeeLoq rolling code from paired 433MHz fob | Must
F-02 | Toggle relay between ARMED (open) and UNLOCKED (closed) on valid code | Must
F-03 | Power-on default state: ARMED (fail-secure) | Must
F-04 | Pair up to 4 key fobs via learn button | Must
F-05 | Erase all paired fobs via 10-sec learn button hold | Must
F-06 | Reject replayed or unknown codes (rolling code window) | Must
F-07 | LED indicates armed (red), unlocked (green), pairing, errors | Must
F-08 | Retain state and paired fobs across power cycles (EEPROM) | Must
F-09 | Accept fob signal at ≥10m range in open air | Should
F-10 | Audible buzzer: single beep (lock), double-beep (unlock), error buzz | Must

### Phase 2 Requirements (LoRa Remote Access)

ID | Requirement | Priority
L-01 | SX1278 time-shares ASK (KeeLoq) and LoRa modes; fob latency < 100ms | Must
L-02 | LoRaWAN Class A uplink: lock state, battery voltage, temperature | Must
L-03 | LoRaWAN downlink: remote lock/unlock commands with AES-128 | Must
L-04 | Telemetry interval: configurable, default 15 min | Should
L-05 | Tamper detection event (voltage drop / power cycle) → immediate uplink | Should
L-06 | LoRa range: ≥2 km urban, ≥10 km line-of-sight | Should
L-07 | Phase 2 firmware runs on same PCB — no hardware changes needed | Must

### Sensor & Zone Requirements

ID | Requirement | Priority
S-01 | NTC thermistor (ADC6) measures ambient temperature ±2°C over -20 to +60°C range | Should
S-02 | LDR photoresistor (ADC7) detects enclosure tamper — light threshold triggers alert | Should
S-03 | 5 zone inputs (J6) accept NO/NC contact sensors (reed switches, motion, etc.) | Should
S-04 | Zone inputs use internal pullups — external wiring is 2-wire (signal + GND) | Should
S-05 | Zone state changes trigger immediate LoRa uplink (Phase 2) or buzzer alert (Phase 1) | Should
S-06 | Temperature and light readings included in periodic telemetry uplink (Phase 2) | Could

### Electrical Requirements

ID | Requirement | Spec
E-01 | Input voltage range | 9-16 VDC (12V nominal from accessory circuit)
E-02 | Quiescent current (armed) | < 25 mA
E-03 | Relay contact rating | ≥ 10A @ 30VDC (motor controller enable wire)
E-04 | Input protection | TVS diode, reverse polarity protection
E-05 | Operating temperature | -20°C to +60°C

### Mechanical / Environmental Requirements

ID | Requirement | Spec
M-01 | Enclosure IP rating | IP67 minimum
M-02 | Enclosure size | ≤ 80 x 50 x 25 mm
M-03 | Mounting | No-drill install (zip-tie + velcro kit included)
M-04 | Vibration | Survive motorcycle vibration (potted PCB)
M-05 | Cable entry | Sealed cable glands, strain-relieved
M-06 | LED visible without opening enclosure | Translucent window on top face

## 12. Block Diagram

## 13. What Ships in the Box

MotoKey Basic — $89

- 1x MotoKey controller (IP67 sealed)
- 2x KeeLoq key fobs (CR2032 included)
- 1x Wire harness (12V power + relay, pre-crimped, 60cm)
- 1x 433MHz wire antenna (15cm, adhesive base)
- 4x heavy-duty zip ties (UV-rated)
- 2x 3M VHB adhesive pads
- 1x quick-start card (3 steps, waterproof)

Install Time: 15 minutes

1. Mount box under seat (zip-tie or velcro)
2. Tap 12V from accessory circuit (splice connector included)
3. Cut enable wire to motor controller, connect through relay (COM + NO)
4. Stick antenna near seat hinge
5. Pair fobs (press learn, press fob, done)

## 14. BOM Summary

Item | Qty | Unit Cost | Total
PCB (assembled, 2-layer) | 1 | $4.50 | $4.50
ATmega328P-AU (TQFP-32) | 1 | $1.80 | $1.80
AMS1117-5.0 + passives | 1 set | $0.60 | $0.60
SRD-05VDC-SL-C relay | 1 | $0.80 | $0.80
SX1278 LoRa/ASK radio module | 1 | $3.00 | $3.00
Passive piezo buzzer + R5 (100Ω) | 1 | $0.30 | $0.30
NTC thermistor + LDR + pullup resistors (R6-R8) | 1 set | $0.40 | $0.40
Zone input header (J6, 7-pin) | 1 | $0.10 | $0.10
+ MCP73831 charger + USB Micro-B + Schottky D3 + C6 + R9 | 1 set | $1.20 | $1.20
+ LiPo battery cell (500mAh) | 1 | $2.50 | $2.50
COGS (with battery option) | | | $26.20
IP67 ABS enclosure + gasket | 1 | $2.50 | $2.50
Cable glands, wire, connectors | 1 set | $1.50 | $1.50
HCS301 KeeLoq key fobs | 2 | $3.00 | $6.00
Mounting kit (zip ties, VHB, antenna) | 1 | $1.00 | $1.00
COGS (Basic — kill switch / deadbolt) | | | $22.50
Retail $89 → Gross Margin | | | 75%
+ GPS receiver module (u-blox NEO-6M or ATGM336H, optional) | 1 | $3.00 | $3.00
+ 1.54" e-paper display module (optional) | 1 | $5.00 | $5.00
COGS (Laundry — with e-paper + no fobs) | | | $21.50

## 15. Phase 2 Use Cases

Phase 2 firmware adds LoRa time-sharing to the same PCB. The SX1278 alternates between ASK (fob listening) and LoRa (long-range telemetry + remote commands). A LoRaWAN gateway within range connects the controller to the internet.

E-Moto Remote Kill & Tracking

Remote lock/unlock via phone app through LoRaWAN downlink. Periodic uplink reports GPS (if external module added), battery voltage, temperature, and lock state. Theft alert on tamper (light sensor) or unexpected motion (zone input).

Rental Property Security

Controller as alarm panel: reed switches on doors/windows (zone inputs), light sensor for tamper, temperature for freeze/heat alerts. Zone events trigger immediate LoRa uplink → push notification to landlord. Remote arm/disarm between tenants.

Coin-Op Laundry Payment

E-paper displays a static LNURL QR code. Tenant scans → Lightning payment → server sends LoRa downlink → relay enables machine for one cycle. No coins, no app install, no Bluetooth pairing. Works with any Lightning wallet.

Tip Jar / Donation Box

E-paper QR on a countertop device. Customer scans, pays any amount over Lightning. Display updates with a thank-you message or running total. Zero ongoing cost — LoRa backhaul, no WiFi or cellular needed.

Vehicle / Asset GPS Tracker

Periodic LoRa uplink with location (external GPS module on a zone input or serial), temperature, and motion state. Long battery life at SF12 with one uplink every 15 min. Covers trailers, generators, construction equipment.

Water Leak & Environmental Monitor

Conductive probe on a zone input detects water. NTC thermistor monitors pipe temperature. LoRa uplink on state change — alert before damage. Deploy in basements, under sinks, near water heaters. Battery-powered via USB-charged LiPo — no wiring needed.

Battery mode enables all standalone use cases — water leak, tip jar, GPS tracker. USB recharge via any phone charger. Low-power firmware sleeps between LoRa uplinks, targeting weeks of battery life on a 1000mAh cell at 15-minute telemetry intervals.

Updated 2026-03-10 — MotoKey hardware system design v6 (buzzer + LoRa + e-paper + sensors + zones + battery + GPS)

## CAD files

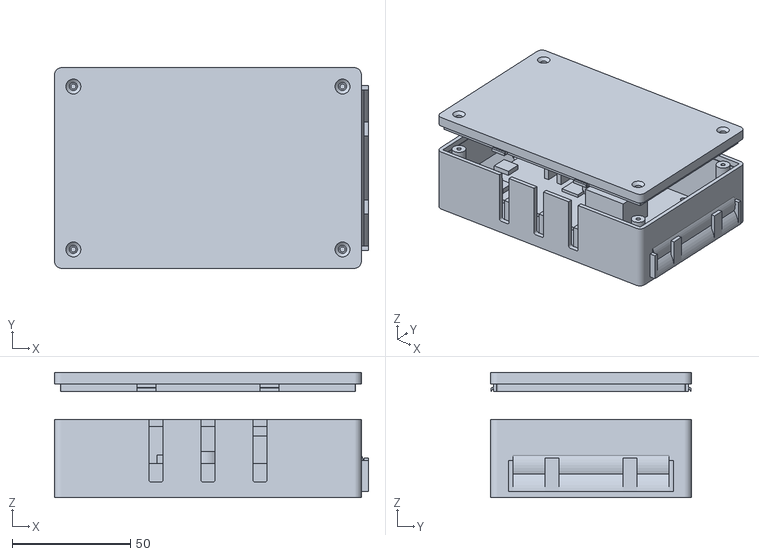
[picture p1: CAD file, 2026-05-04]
hardware/enclosure.stl
133.0 x 85.0 x 53.0

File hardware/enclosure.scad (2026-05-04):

// MotoKey Lock Box — Castellated Finger Joint Enclosure (2 pieces, no drilling)
// Base and lid interlock like interlaced fingers. Gaps at connector locations
// form cable/port openings. Where no openings needed, fingers mesh tightly.
//
// v3 2026-03-10
// Units: mm
// Print: PETG or ABS, 0.2mm layers, 3 walls, 20% infill
// Orientation: both pieces print open-side-up (fingers point up)
// No supports needed — all features are vertical extrusions
// Render: F5 preview, F6 full render

/* [Enclosure] */
ext_l = 140;            // length (x) — fits PCB + battery side by side
ext_w = 75;             // width (y) — fits 60mm PCB + clearance
ext_h = 38;             // total height (z)
wall = 2.5;             // wall thickness
corner_r = 3;           // external corner radius
split_z = 19;           // z height where base ends and lid begins

/* [Finger Joint] */
finger_w = 8;           // finger width along wall
finger_tol = 0.2;       // clearance per side for fit
finger_depth = 8;       // how far fingers extend into mating part

/* [PCB] */
pcb_l = 95;
pcb_w = 60;
pcb_t = 1.6;
pcb_off_x = 5;          // PCB offset from inner left wall
pcb_off_y = 5;          // PCB offset from inner front wall
standoff_h = 6;
standoff_d = 6;
standoff_hole = 2.8;
standoff_inset = 4;     // from PCB edge (matches M3 mounting holes)

/* [Battery] */
batt_d = 18.5;          // 18650 diameter + clearance
batt_l = 66;            // 18650 length + 1mm
cradle_wall = 2;

/* [Mounting Flanges] */
flange_l = 22;
flange_w = 10;
flange_t = 3.5;
flange_hole = 4.2;      // M4

/* [Rendering] */
show_base = true;
show_lid = true;
show_pcb = true;
show_battery = true;
explode = 20;           // 0 = assembled, >0 = exploded view
$fn = 48;

// ============================================================
// Derived dimensions
// ============================================================
int_l = ext_l - 2*wall;
int_w = ext_w - 2*wall;
pcb_x = wall + pcb_off_x;
pcb_y = wall + pcb_off_y;
pcb_z = wall + standoff_h;

// Battery position — right of PCB, centered in y
batt_cx = wall + pcb_off_x + pcb_l + 8 + batt_d/2;
batt_cy = ext_w / 2;

// ============================================================
// PCB connector positions (from gen_pcb.py PLACEMENTS)
// Mapped to enclosure walls where they need openings
//
// PCB origin in enclosure: (pcb_x, pcb_y)
// PCB coords → enclosure coords: ex = pcb_x + px, ey = pcb_y + (pcb_w - py)
//   (y flipped because PCB y=0 is top, enclosure y=0 is front)
// ============================================================

// --- LEFT WALL (x = 0) openings ---
// J7 USB Micro-B at PCB (5, 34) — on left edge, rotated 90°
// USB connector is ~9mm wide, 6mm tall
usb_ex = 0;  // on left wall
usb_ey = pcb_y + (pcb_w - 34);  // ~31mm from front
usb_width = 12;
usb_height = 8;

// --- TOP WALL (y = ext_w) openings ---
// J1 12V input at PCB (12, 10) — near top edge
j1_ex = pcb_x + 12;
j1_width = 10;  // screw terminal

// --- RIGHT WALL (x = ext_l) openings ---
// J2 relay output at PCB (88, 10) — near top-right
j2_ex = pcb_x + 88;  // but this is relative to right wall
j2_width = 10;

// --- BOTTOM WALL (y = 0) openings ---
// J4 SX1278 at PCB (38, 40→58) — headers extend toward bottom
// J5 E-paper at PCB (46, 40→58)
// J6 Zones at PCB (62, 40→55)
// J8 GPS at PCB (54, 44→52)
// These are pin headers — wires route out bottom

// --- BACK WALL (y = ext_w) ---
// LED1, LED2 at PCB y=8 → enclosure y = pcb_y + (60-8) = ~57 (near back)
// SW1 learn button at PCB (56, 8) → near back wall
// BZ1 buzzer at PCB (66, 8) → near back wall

// ============================================================
// Connector opening definitions
// Each: [wall, position_along_wall, width, z_bottom, z_top]
// wall: 0=front(y=0), 1=right(x=ext_l), 2=back(y=ext_w), 3=left(x=0)
// ============================================================

// Opening specs: [wall_id, center_pos_along_wall, opening_width, z_start, z_end]
openings = [
    // J7 USB — left wall
    [3, pcb_y + (pcb_w - 34), 14, pcb_z - 1, pcb_z + 6],
    // J1 12V screw terminal — back wall (PCB y=10 → near back)
    [2, pcb_x + 12, 12, pcb_z, pcb_z + 10],
    // J2 relay output — back wall
    [2, pcb_x + 88, 12, pcb_z, pcb_z + 10],
    // LED1+LED2 light pipes — back wall
    [2, pcb_x + 45, 18, pcb_z + 2, pcb_z + 6],
    // Cable entry — front wall (for sensor/zone wires)
    [0, ext_l * 0.35, 10, 4, 14],
    [0, ext_l * 0.6, 10, 4, 14],
    // Battery wires — right wall
    [1, ext_w * 0.5, 10, 4, 14],
];

// ============================================================
// Primitives
// ============================================================

module rounded_box(l, w, h, r) {
    hull()
        for (x = [r, l-r], y = [r, w-r])
            translate([x, y, 0])
                cylinder(r=r, h=h);
}

// ============================================================
// Finger joint generation
//
// For each wall, we divide it into segments of finger_w.
// Base gets even-numbered fingers (0, 2, 4...) pointing up.
// Lid gets odd-numbered fingers (1, 3, 5...) pointing down.
// Where an opening exists, BOTH base and lid omit the finger,
// leaving a hole.
// ============================================================

// Check if a finger at position [start, end] along a wall overlaps any opening
function finger_overlaps_opening(wall_id, fstart, fend) =
    let(results = [for (o = openings)
        if (o[0] == wall_id)
            let(ostart = o[1] - o[2]/2, oend = o[1] + o[2]/2)
                (fstart < oend && fend > ostart) ? 1 : 0
    ])
    len([for (r = results) if (r == 1) r]) > 0;


// Fingers for front/back walls (along X axis, full length including corners)
module x_wall_fingers(wall_id, y_pos, z_base, is_base) {
    n = floor(ext_l / finger_w);
    fw = ext_l / n;
    for (i = [0 : n - 1]) {
        fstart = i * fw;
        fend = fstart + fw;
        my_finger = is_base ? (i % 2 == 0) : (i % 2 == 1);
        has_opening = finger_overlaps_opening(wall_id, fstart, fend);
        if (my_finger && !has_opening) {
            translate([fstart + finger_tol, y_pos, z_base])
                cube([fw - 2 * finger_tol, wall, finger_depth]);
        }
    }
}

// Fingers for left/right walls (along Y axis, skip corners to avoid overlap)
module y_wall_fingers(wall_id, x_pos, z_base, is_base) {
    inner_start = wall;
    inner_len = ext_w - 2 * wall;
    n = max(1, floor(inner_len / finger_w));
    fw = inner_len / n;
    for (i = [0 : n - 1]) {
        fstart = inner_start + i * fw;
        fend = fstart + fw;
        my_finger = is_base ? (i % 2 == 0) : (i % 2 == 1);
        has_opening = finger_overlaps_opening(wall_id, fstart, fend);
        if (my_finger && !has_opening) {
            translate([x_pos, fstart + finger_tol, z_base])
                cube([wall, fw - 2 * finger_tol, finger_depth]);
        }
    }
}

// Slot cutters — remove wall material where the OPPOSING part's fingers go
// For base: cut slots where lid fingers (odd) will drop in
// For lid: cut slots where base fingers (even) will poke up into

module x_wall_slots(wall_id, y_pos, is_base) {
    n = floor(ext_l / finger_w);
    fw = ext_l / n;
    for (i = [0 : n - 1]) {
        fstart = i * fw;
        // The opposing part's finger: base cuts for lid (odd), lid cuts for base (even)
        opp_finger = is_base ? (i % 2 == 1) : (i % 2 == 0);
        has_opening = finger_overlaps_opening(wall_id, fstart, fstart + fw);
        if (opp_finger && !has_opening) {
            // Cut a slot finger_depth deep into this wall
            translate([fstart, y_pos - 0.01, is_base ? split_z - finger_depth : split_z])
                cube([fw, wall + 0.02, finger_depth + 0.01]);
        }
    }
}

module y_wall_slots(wall_id, x_pos, is_base) {
    inner_start = wall;
    inner_len = ext_w - 2 * wall;
    n = max(1, floor(inner_len / finger_w));
    fw = inner_len / n;
    for (i = [0 : n - 1]) {
        fstart = inner_start + i * fw;
        opp_finger = is_base ? (i % 2 == 1) : (i % 2 == 0);
        has_opening = finger_overlaps_opening(wall_id, fstart, fstart + fw);
        if (opp_finger && !has_opening) {
            translate([x_pos - 0.01, fstart, is_base ? split_z - finger_depth : split_z])
                cube([wall + 0.02, fw, finger_depth + 0.01]);
        }
    }
}

// ============================================================
// Base
// ============================================================

module base() {
    difference() {
        union() {
            // Floor + lower walls up to split_z
            difference() {
                rounded_box(ext_l, ext_w, split_z, corner_r);
                translate([wall, wall, wall])
                    rounded_box(int_l, int_w, split_z, max(corner_r - wall, 0.5));
            }
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

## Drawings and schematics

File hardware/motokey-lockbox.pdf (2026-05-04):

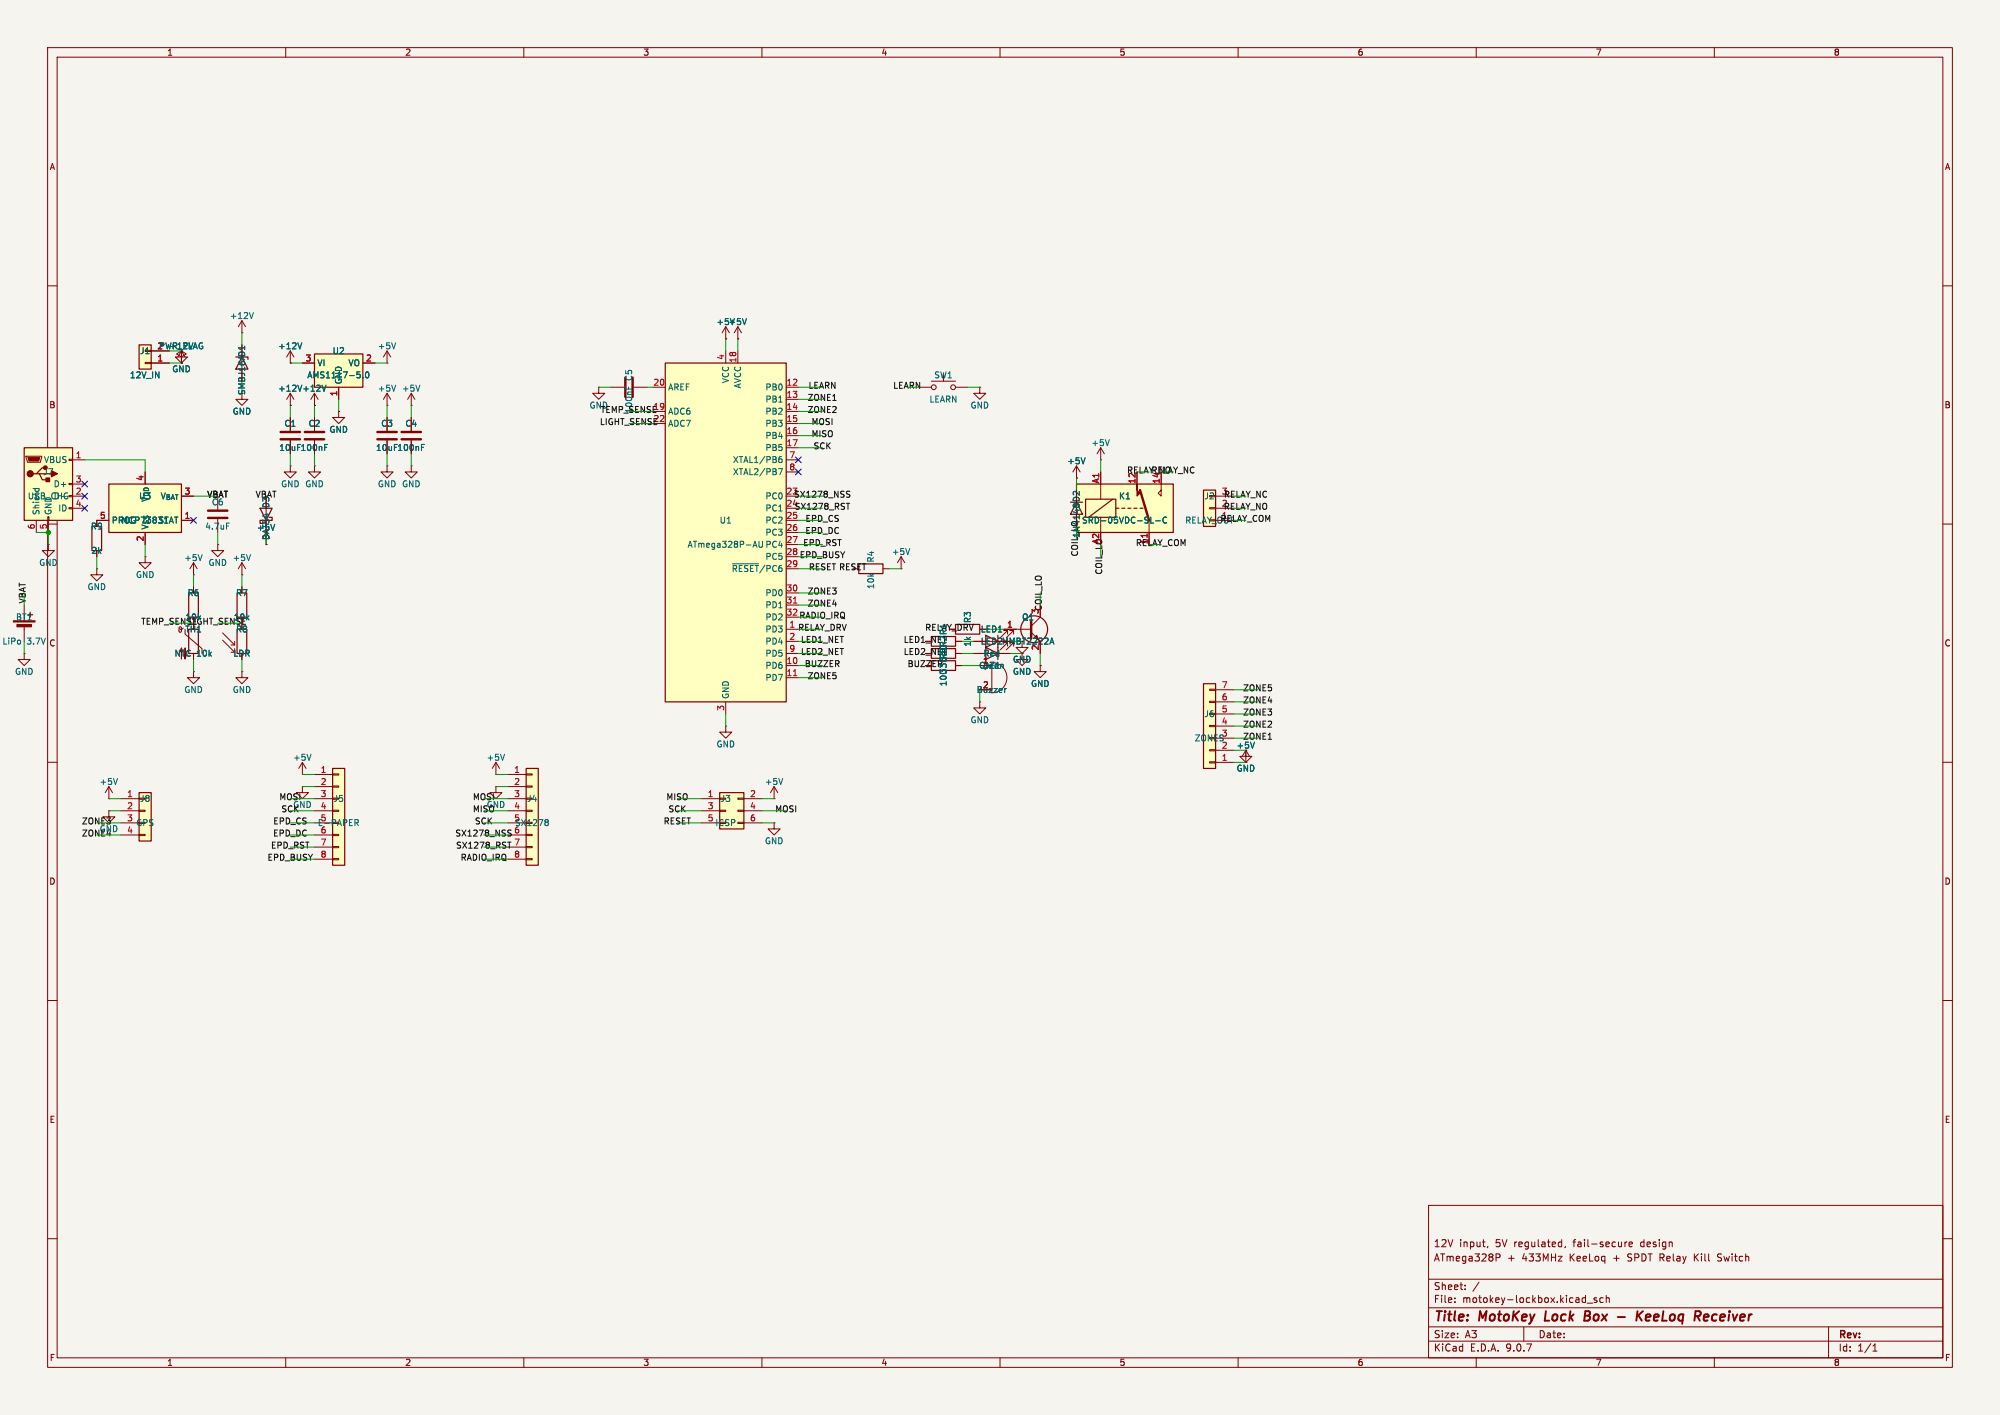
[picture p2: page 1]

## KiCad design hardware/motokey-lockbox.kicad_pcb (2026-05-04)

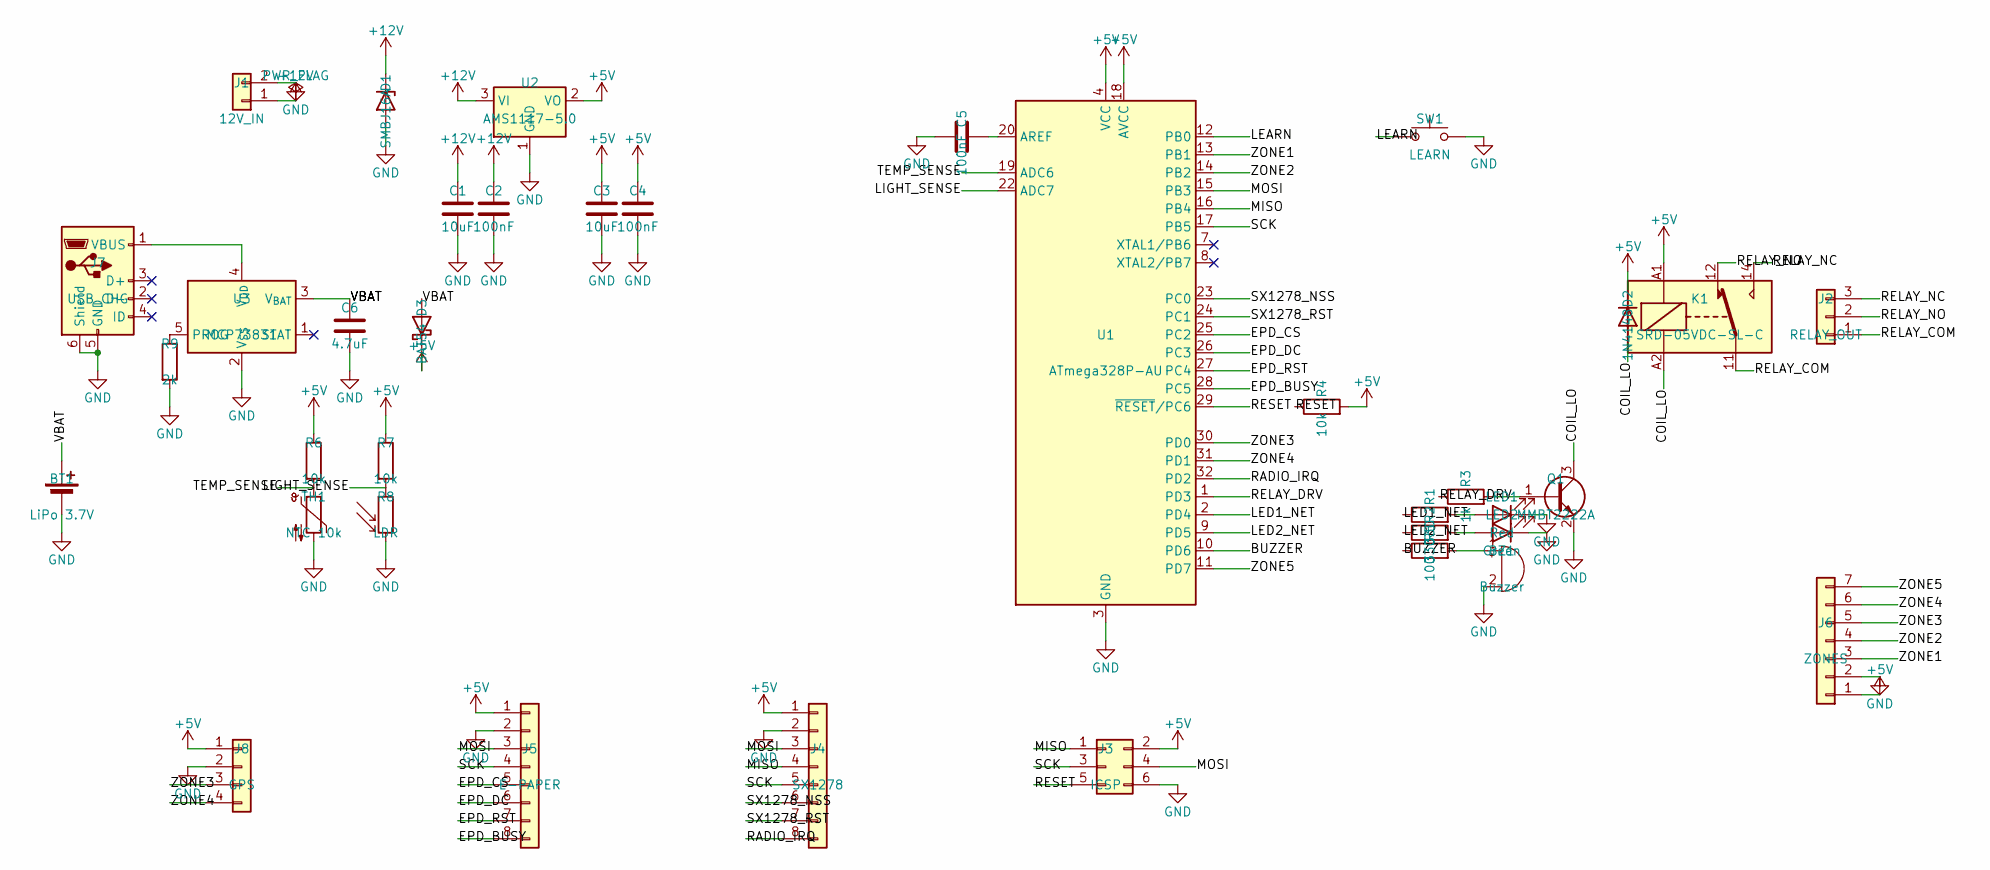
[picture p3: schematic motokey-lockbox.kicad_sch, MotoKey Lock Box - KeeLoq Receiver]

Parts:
BT1: LiPo 3.7V; BatteryHolder_Keystone_1042_1x18650
BZ1: Buzzer; Buzzer_12x9.5RM7.6
C1, C3: 10uF; C_0805_2012Metric
C2, C4, C5: 100nF; C_0805_2012Metric
C6: 4.7uF; C_0805_2012Metric
D1: SMBJ16A; D_SMB_Handsoldering
D2: 1N4148; D_SOD-123
D3: BAT54; D_SOD-123
J1: 12V_IN; PinHeader_1x02_P2.54mm_Vertical
J2: RELAY_OUT; PinHeader_1x03_P2.54mm_Vertical
J3: ICSP; PinHeader_2x03_P2.54mm_Vertical
J4: SX1278; PinHeader_1x08_P2.54mm_Vertical
J5: E-PAPER; PinHeader_1x08_P2.54mm_Vertical
J6: ZONES; PinHeader_1x07_P2.54mm_Vertical
J7: USB_CHG; USB_Micro-B_Molex-105017-0001
J8: GPS; PinHeader_1x04_P2.54mm_Vertical
K1: SRD-05VDC-SL-C; Relay_SPDT_Finder_40.11
LED1: Red; LED_0805_2012Metric
LED2: Green; LED_0805_2012Metric
Q1: MMBT2222A; SOT-23
R1, R2: 330; R_0805_2012Metric
R3: 1k; R_0805_2012Metric
R4, R6, R7: 10k; R_0805_2012Metric
R5: 100; R_0805_2012Metric
R8: LDR; R_0805_2012Metric
R9: 2k; R_0805_2012Metric
SW1: LEARN; SW_SPST_PTS645Sx43SMTR92
TH1: NTC 10k; R_0805_2012Metric
U1: ATmega328P-AU; TQFP-32_7x7mm_P0.8mm
U2: AMS1117-5.0; SOT-223-3_TabPin2
U3: MCP73831; SOT-23-5

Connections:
+5V: C3.1, C4.1, D2.1 (K), D3.1 (K), J3.2, J4.1, J5.1, J6.1, J8.1, K1.A1, R4.2, R6.1, R7.1, U1.4 (VCC), U1.6 (VCC), U1.18 (AVCC), U2.2 (VO)
+12V: C1.1, C2.1, D1.1 (K), J1.1, U2.3 (VI)
/BUZZER: R5.1, U1.10 (PD6)
/COIL_LO: D2.2 (A), K1.A2, Q1.3 (C)
/EPD_BUSY: J5.8, U1.28 (PC5)
/EPD_CS: J5.5, U1.25 (PC2)
/EPD_DC: J5.6, U1.26 (PC3)
/EPD_RST: J5.7, U1.27 (PC4)
/LEARN: SW1.1, U1.12 (PB0)
/LED1_NET: R1.1, U1.2 (PD4)
/LED2_NET: R2.1, U1.9 (PD5)
/LIGHT_SENSE: R7.2, R8.1, U1.22 (ADC7)
/MISO: J3.1, J4.4, U1.16 (PB4)
/MOSI: J3.4, J4.3, J5.3, U1.15 (PB3)
/RADIO_IRQ: J4.8, U1.32 (PD2)
/RELAY_COM: J2.1, K1.11
/RELAY_DRV: R3.1, U1.1 (PD3)
/RELAY_NC: J2.3, K1.14
/RELAY_NO: J2.2, K1.12
/RESET: J3.5, R4.1, U1.29 (~RESET/PC6)
/SCK: J3.3, J4.5, J5.4, U1.17 (PB5)
/SX1278_NSS: J4.6, U1.23 (PC0)
/SX1278_RST: J4.7, U1.24 (PC1)
/TEMP_SENSE: R6.2, TH1.1, U1.19 (ADC6)
/VBAT: BT1.1 (+), C6.1, D3.2 (A), U3.3 (V_{BAT})
/ZONE1: J6.3, U1.13 (PB1)
/ZONE2: J6.4, U1.14 (PB2)
/ZONE3: J6.5, J8.3, U1.30 (PD0)
/ZONE4: J6.6, J8.4, U1.31 (PD1)
/ZONE5: J6.7, U1.11 (PD7)
GND: BT1.2 (-), BZ1.2 (-), C1.2, C2.2, C3.2, C4.2, C5.1, C6.2, D1.2 (A), J1.2, J3.6, J4.2, J5.2, J6.2, J7.5 (GND), J7.6 (Shield), J8.2, LED1.1 (K), LED2.1 (K), Q1.2 (E), R8.2, R9.2, SW1.2, TH1.2, U1.3 (GND), U1.5 (GND), U1.21 (GND), U2.1 (GND), U3.2 (V_{SS})
unnamed: BZ1.1 (+), R5.2
unnamed: J7.1 (VBUS), U3.4 (V_{DD})
unnamed: LED1.2 (A), R1.2
unnamed: LED2.2 (A), R2.2
unnamed: Q1.1 (B), R3.2
unnamed: C5.2, U1.20 (AREF)
unnamed: R9.1, U3.5 (PROG)

Board: 2 copper layers, 41 parts (0 on the bottom side), 38 nets, no tracks yet.

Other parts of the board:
MH1, MH2, MH3, MH4: MountingHole; MountingHole_3.2mm_M3

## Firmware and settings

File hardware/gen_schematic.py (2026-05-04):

#!/usr/bin/env python3
"""Generate MotoKey Lock Box KiCad schematic.

KeeLoq receiver + relay kill switch for e-motorcycles.
  U1: ATmega328P-A (TQFP-32), 8MHz internal osc
  U2: AMS1117-5.0 (SOT-223) LDO
  U3: MCP73831-2-OT (SOT-23-5) LiPo charger
  Q1: MMBT2222A (SOT-23) NPN relay driver
  K1: Relay_SPDT, 5V coil
  D1: Zener/TVS 16V input protection
  D2: 1N4148 flyback diode
  D3: Schottky diode (battery → +5V power path)
  BT1: LiPo battery cell (3.7V)
  LED1/LED2: status LEDs (red=armed, green=unlocked)
  BZ1: passive piezo buzzer (PWM on PD6/OC0A)
  J4: SX1278 LoRa/ASK radio module (8-pin header)
  J5: 1.54" e-paper display (8-pin header, optional)
  J6: Zone inputs for NO/NC contact sensors (7-pin header)
  J7: USB Micro-B (charging input for LiPo)
  RT1: NTC thermistor (10k, tamper/ambient temp)
  R_LDR: LDR photoresistor (light/tamper detect)
  R1-R9, C1-C6, SW1, J1-J7, BT1
"""
import uuid, os, re, sys

KICAD_SYMS = "/Applications/KiCad.app/Contents/SharedSupport/symbols"
HERE = os.path.dirname(os.path.abspath(__file__))

def uid():
    return str(uuid.uuid4())

# ============================================================
# Symbol extraction from KiCad libraries
# ============================================================

def _find_symbol(text, name):
    """Find and extract a top-level symbol by balanced parens."""
    target = f'(symbol "{name}"'
    pos = 0
    while True:
        idx = text.find(target, pos)
        if idx < 0:
            return None
        # Ensure exact name match (not a sub-symbol like Name_0_1)
        end_of_name = idx + len(target)
        if end_of_name < len(text) and text[end_of_name] not in '\n\r \t':
            pos = end_of_name
            continue
        # Extract by balanced parens
        depth = 0
        for i in range(idx, len(text)):
            if text[i] == '(':
                depth += 1
            elif text[i] == ')':
                depth -= 1
                if depth == 0:
                    return text[idx:i+1]
        break
    return None

def _get_sub_symbols(sym_text, name):
    """Extract sub-symbols (Name_0_1, Name_1_1, etc.)."""
    subs = []
    target = f'(symbol "{name}_'
    pos = 0
    while True:
        idx = sym_text.find(target, pos)
        if idx < 0:
            break
        depth = 0
        for i in range(idx, len(sym_text)):
            if sym_text[i] == '(':
                depth += 1
            elif sym_text[i] == ')':
                depth -= 1
                if depth == 0:
                    subs.append(sym_text[idx:i+1])
                    pos = i + 1
                    break
    return subs

def flatten(lib_file, child_name):
    """Extract symbol from library, flattening 'extends' if needed."""
    with open(f"{KICAD_SYMS}/{lib_file}") as f:
        text = f.read()

    child = _find_symbol(text, child_name)
    if child is None:
        raise ValueError(f"Symbol '{child_name}' not found in {lib_file}")

    m = re.search(r'\(extends "([^"]+)"\)', child)
    if not m:
        return child  # already flat

    parent_name = m.group(1)
    # Recursively flatten parent if it also extends
    parent = _find_symbol(text, parent_name)
    if parent is None:
        raise ValueError(f"Parent '{parent_name}' not found in {lib_file}")
    pm = re.search(r'\(extends "([^"]+)"\)', parent)
    if pm:
        parent = flatten(lib_file, parent_name)

    # Get parent sub-symbols, rename to child
    subs = _get_sub_symbols(parent, parent_name)
    renamed = [re.sub(rf'"{re.escape(parent_name)}_(\d+_\d+)"', rf'"{child_name}_\1"', s) for s in subs]

    # Remove extends directive from child
    result = re.sub(r'\n?\s*\(extends "[^"]+"\)', '', child)

    # Copy missing attributes from parent
    for attr in ['exclude_from_sim', 'in_bom', 'on_board']:
        if attr not in result:
            am = re.search(rf'\({attr}\s+\w+\)', parent)
            if am:
                nl = result.find('\n')
                result = result[:nl+1] + '\t\t\t' + am.group(0) + '\n' + result[nl+1:]

    # Also copy pin_numbers/pin_names if present in parent but not child
    for attr in ['pin_numbers', 'pin_names']:
        if attr not in result:
            # Extract the full block
            am_idx = parent.find(f'({attr}')
            if am_idx >= 0:
                depth = 0
                for i in range(am_idx, len(parent)):
                    if parent[i] == '(':
                        depth += 1
                    elif parent[i] == ')':
                        depth -= 1
                        if depth == 0:
                            block = parent[am_idx:i+1]
                            nl = result.find('\n')
                            result = result[:nl+1] + '\t\t\t' + block + '\n' + result[nl+1:]
                            break

    # Insert sub-symbols before closing paren
    close = result.rstrip().rfind(')')
    sub_text = '\n'.join('\t\t\t' + s for s in renamed)
    result = result[:close] + '\n' + sub_text + '\n\t\t' + result[close:]

    return result

def lib_symbol(lib_file, name, lib_prefix):
    """Get symbol for schematic lib_symbols section with proper prefix."""
    sym = flatten(lib_file, name)
    full = f"{lib_prefix}:{name}"
    # Only rename the top-level symbol name; sub-symbols keep original names
    sym = sym.replace(f'(symbol "{name}"', f'(symbol "{full}"', 1)
    # Add two tabs prefix (preserving internal indentation from library)
    lines = sym.split('\n')
    return '\n'.join('\t\t' + line for line in lines)

# ============================================================
# Pin endpoint transform
# ============================================================

def pxy(sx, sy, px, py, theta=0):
    """Transform library pin (px,py) to schematic coords for symbol at (sx,sy) rotation theta."""
    if theta == 0:   return (round(sx + px, 2), round(sy - py, 2))
    if theta == 90:  return (round(sx - py, 2), round(sy - px, 2))
    if theta == 180: return (round(sx - px, 2), round(sy + py, 2))
    if theta == 270: return (round(sx + py, 2), round(sy + px, 2))
    return (round(sx + px, 2), round(sy - py, 2))

# ============================================================
# Schematic element generators
# ============================================================

ROOT = uid()

def s_wire(x1, y1, x2, y2):
    return (f'\t(wire\n\t\t(pts (xy {x1} {y1}) (xy {x2} {y2}))\n'
            f'\t\t(stroke (width 0) (type default))\n\t\t(uuid "{uid()}")\n\t)')

def s_label(name, x, y, rot=0):
    return (f'\t(label "{name}"\n\t\t(at {x} {y} {rot})\n'
            f'\t\t(effects\n\t\t\t(font\n\t\t\t\t(size 1.27 1.27)\n\t\t\t)\n\t\t)\n'
            f'\t\t(uuid "{uid()}")\n\t)')

def s_nc(x, y):
    return f'\t(no_connect (at {x} {y}) (uuid "{uid()}"))'

def s_junction(x, y):
    return (f'\t(junction\n\t\t(at {x} {y})\n\t\t(diameter 0)\n'
            f'\t\t(color 0 0 0 0)\n\t\t(uuid "{uid()}")\n\t)')
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

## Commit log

2026-02-21 Add hardware architecture & MVP design document
    Full lock box + key fob architecture with real components,
    BOM with pricing at 100-unit scale, margin analysis, security
    protocol diagrams, prototype build plan, and physical layouts.
2026-02-21 Make both pages mobile-friendly
    - Storefront: single-column layout on mobile, scrollable tables
    and diagrams, adjusted typography and spacing
    - Hardware design: scrollable table wrappers for all BOM tables,
    SVG diagrams scroll horizontally, pre blocks sized for small
    screens, full-bleed elements on mobile for max space
2026-02-21 Add comprehensive README with full project documentation
    Requirements, hardware design summary, security protocol,
    BOM with costs, margin analysis, step-by-step build plan
    for Julio, and a concrete plan to sell the first 10 units.
2026-05-04 Add hardware design docs and CLAUDE.md
    [enclosure.scad, enclosure.stl, motokey-lockbox.kicad_pcb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]
2026-05-04 Add gitignore for __pycache__, kicad backups, fp-info-cache
